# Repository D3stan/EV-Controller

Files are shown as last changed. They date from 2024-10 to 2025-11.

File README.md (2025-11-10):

# EV-Controller

This project is an ESP8266/ESP32-based exhaust valve controller for motorcycles. It offers real-time monitoring and configuration through a web interface, utilizing WebSockets for live data communication. The core functionality is to control the motorcycle's exhaust valve based on configurable RPM thresholds.

<table>
  <tr>
    <td>
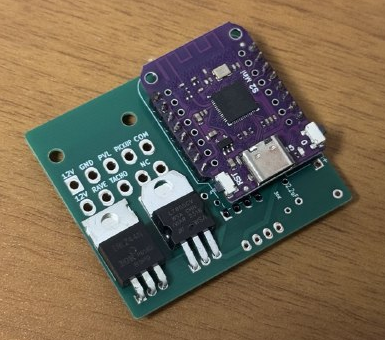
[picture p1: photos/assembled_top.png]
      <br>
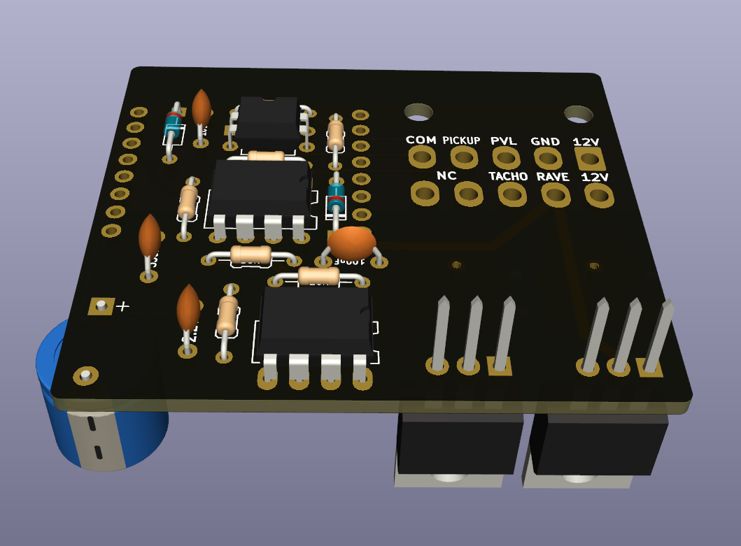
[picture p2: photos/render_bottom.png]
      
    </td>
    <td>
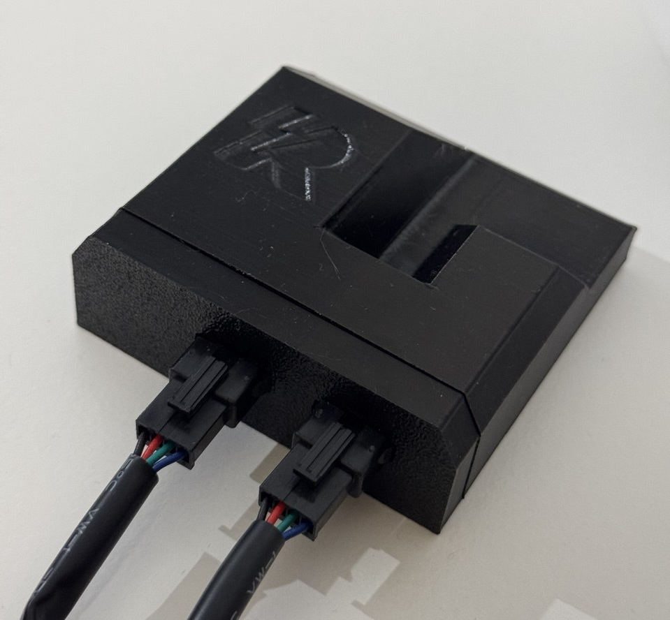
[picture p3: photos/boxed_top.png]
      
    </td>
  </tr>
</table>

## Features

- RPM-based exhaust valve control with configurable opening and closing thresholds.
- Web interface for real-time RPM monitoring and settings adjustment.
- WiFi Access Point (AP) mode for initial setup and configuration.
- WiFi Station (STA) mode to connect to an existing wireless network.
- Secure Over-the-Air (OTA) updates for both firmware and filesystem.
- Manual override for valve control directly from the web interface.

## Hardware Construction

To build the hardware, you will need to manufacture the PCB and source the electronic components.

### 1. PCB Manufacturing

The Gerber files required for PCB production are located in the `pcb/production/gerber.zip` archive. You can upload this file to any PCB manufacturer of your choice.

### 2. Component Sourcing

The list of all necessary components (Bill of Materials) is available in the `pcb/production/bom.csv` file. This file can be used to order parts from electronic component distributors.

### 3. Assembly

Solder the components onto the manufactured PCB. For component placement and orientation, please refer to the following files:

- **Schematic:** `pcb/schema.pdf`
- **KiCad Project:** `pcb/Rave-Controller.kicad_pro` (can be opened with KiCad)

For automated pick-and-place assembly, the `pcb/production/positions.csv` file is also provided.

## Firmware Installation

The firmware is built using PlatformIO.

### Prerequisites

- [Visual Studio Code](https://code.visualstudio.com/)
- [PlatformIO IDE extension](https://platformio.org/install/ide?install=vscode) for VS Code

### Build and Upload

1.  Clone this repository to your local machine.
2.  Open the cloned repository folder in Visual Studio Code.
3.  PlatformIO will automatically detect the `platformio.ini` file and prompt you to install the required project dependencies.
4.  Once dependencies are installed, select the correct environment for your board (e.g., `d1_mini`).
5.  Use the PlatformIO "Upload" task to build and flash the firmware to your device. Alternatively, you can run the following command from the integrated terminal:
    ```bash
    pio run -e d1_mini --target upload
    ```

## Initial Setup

1.  On the first boot, the device will create a Wi-Fi Access Point. The default SSID and password can be found in the source code (`data/config.json`).
2.  Connect your computer or smartphone to this Wi-Fi network.
3.  Open a web browser and navigate to the device's default IP address, which is `42.42.42.42`.
4.  From the web interface, you can configure your home Wi-Fi credentials (SSID and password) and set the desired RPM thresholds for the exhaust valve operation.
5.  After saving the new settings, the device will restart, connect to your specified Wi-Fi network, and begin normal operation.

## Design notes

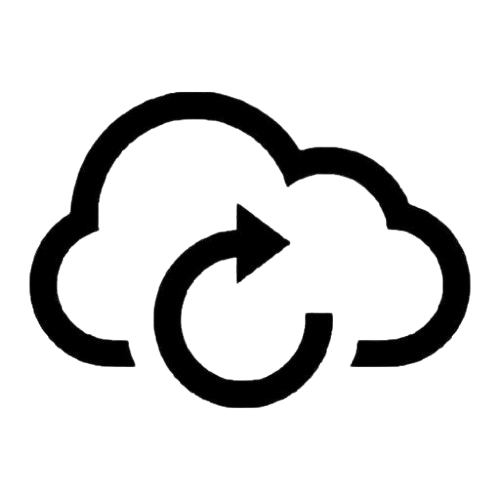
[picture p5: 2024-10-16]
docs/update.png

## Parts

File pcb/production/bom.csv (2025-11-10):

Designator | Footprint | Quantity | Value | LCSC Part #
C1, C5 | C_Disc_D4.3mm_W1.9mm_P5.00mm | 2 | 100nF
C2 | C_Disc_D4.3mm_W1.9mm_P5.00mm | 1 | 330nF
C3 | C_Disc_D4.3mm_W1.9mm_P5.00mm | 1 | 2.2uF
C4 | CP_Radial_D10.0mm_P7.50mm | 1 | 1000uF_50V
D1, D3 | D_DO-34_SOD68_P7.62mm_Horizontal | 2 | D_Schottky
J1 | Molex_Mini-Fit_Jr_5569-10A2_2x05_P4.20mm_Horizontal | 1 | Conn_01x10
Q1 | TO-220-3_Vertical | 1 | IRLZ44N
R1 | R_Axial_DIN0204_L3.6mm_D1.6mm_P7.62mm_Horizontal | 1 | 100k
R2 | R_Axial_DIN0204_L3.6mm_D1.6mm_P7.62mm_Horizontal | 1 | 1k
R3 | R_Axial_DIN0204_L3.6mm_D1.6mm_P7.62mm_Horizontal | 1 | 3k
R4, R7 | R_Axial_DIN0204_L3.6mm_D1.6mm_P7.62mm_Horizontal | 2 | 30k
R5 | R_Axial_DIN0204_L3.6mm_D1.6mm_P7.62mm_Horizontal | 1 | 4.7k
R6 | R_Axial_DIN0204_L3.6mm_D1.6mm_P7.62mm_Horizontal | 1 | 10k
U1 | D1_mini_board | 1 | D1Mini
U2 | TO-220-3_Vertical | 1 | LM7805_TO220
U3 | DIP-8_W7.62mm_LongPads | 1 | LMC662AIN
U4 | DIP-4_W7.62mm | 1 | PC817
U5 | DIP-8_W7.62mm | 1 | TC4422

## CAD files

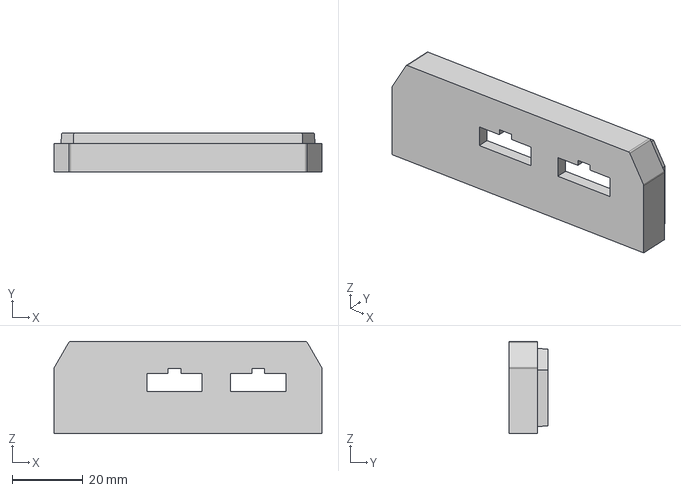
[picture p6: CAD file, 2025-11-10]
pcb/Rave v7.step
75.6 x 11.0 x 26.0 mm

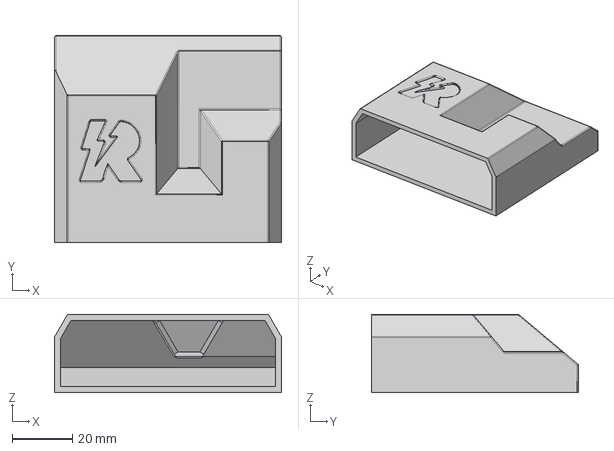
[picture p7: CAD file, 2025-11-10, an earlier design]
pcb/Rave v4.step
75.6 x 68.9 x 26.0 mm

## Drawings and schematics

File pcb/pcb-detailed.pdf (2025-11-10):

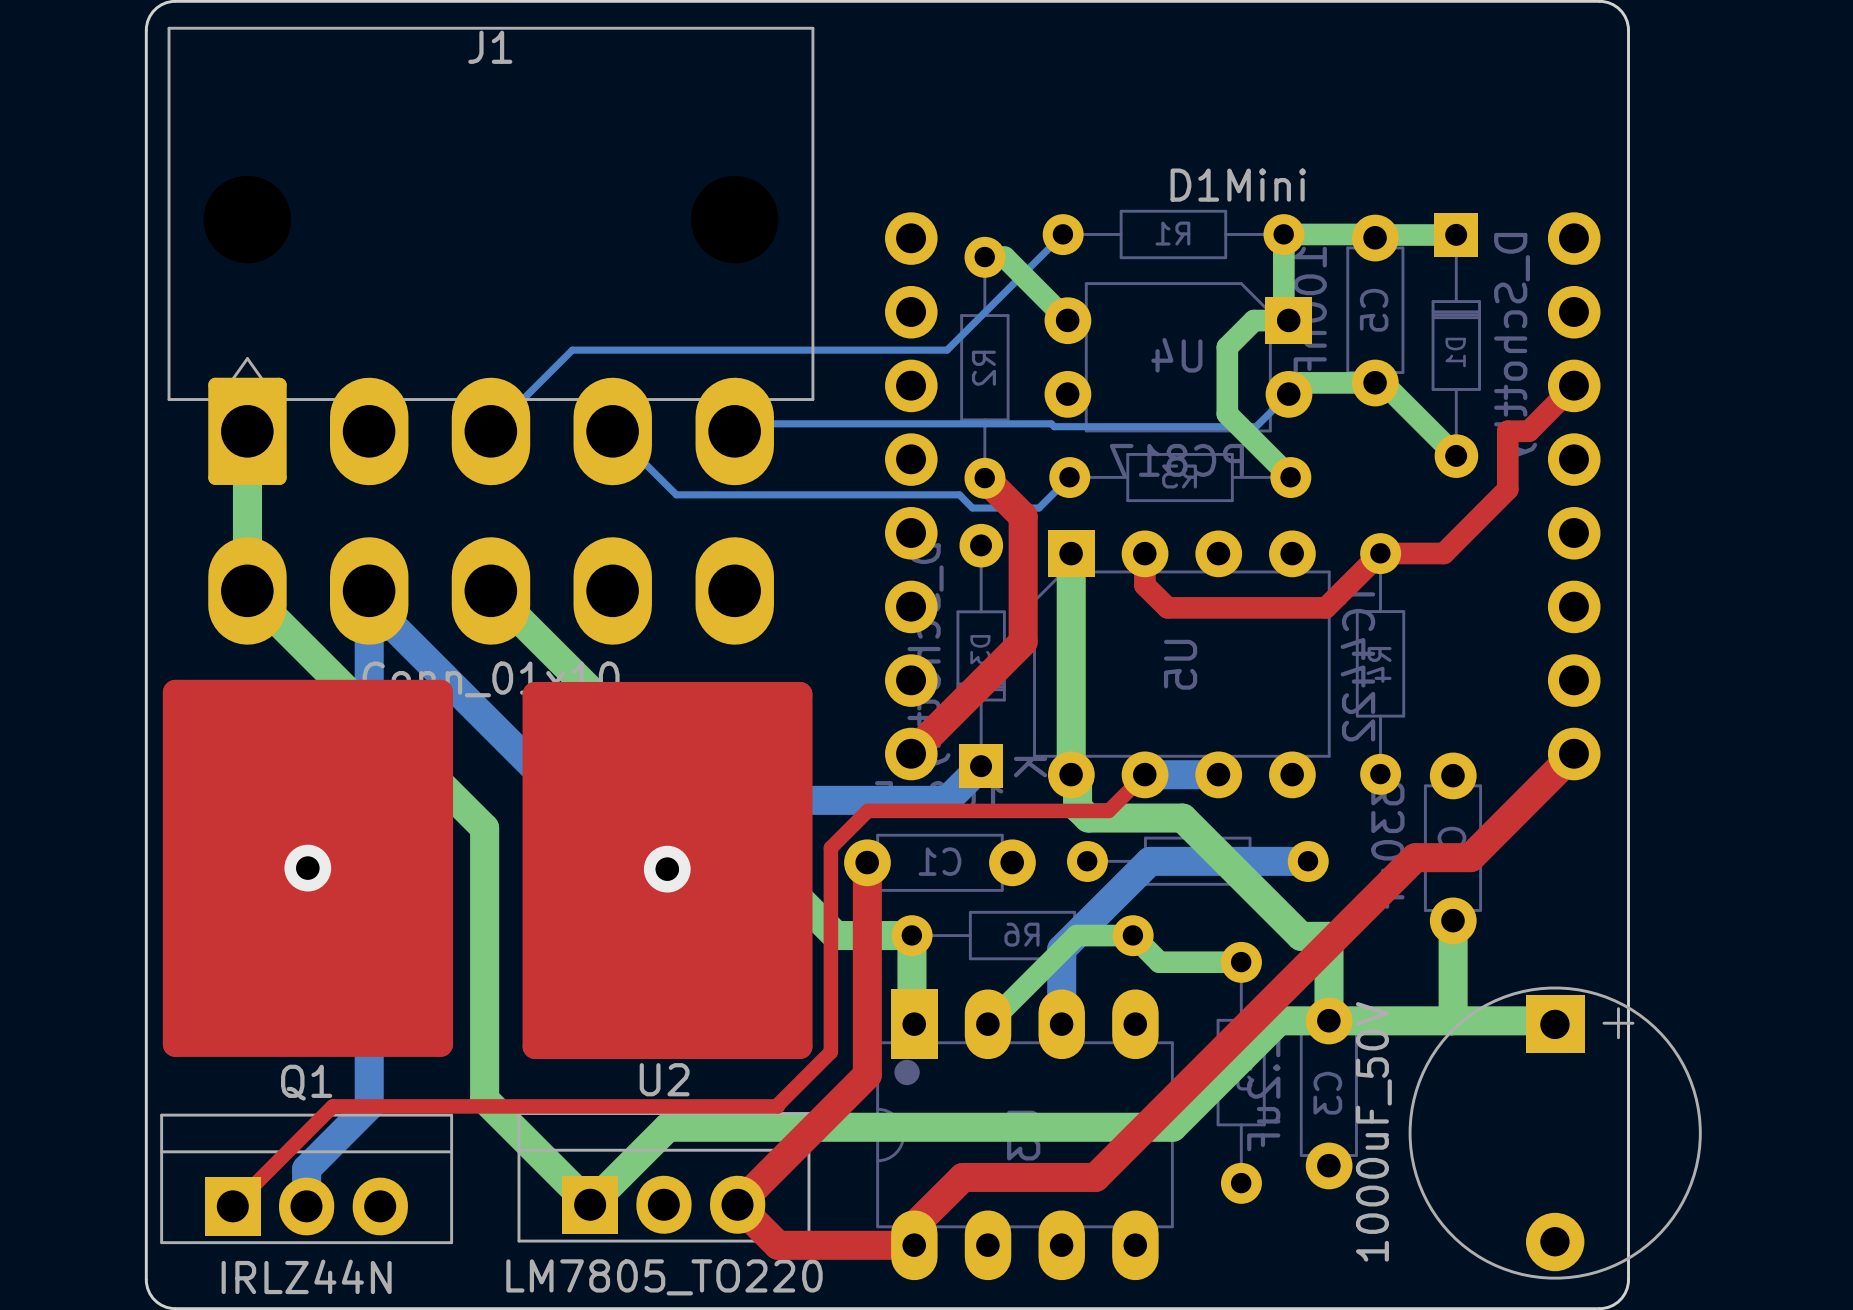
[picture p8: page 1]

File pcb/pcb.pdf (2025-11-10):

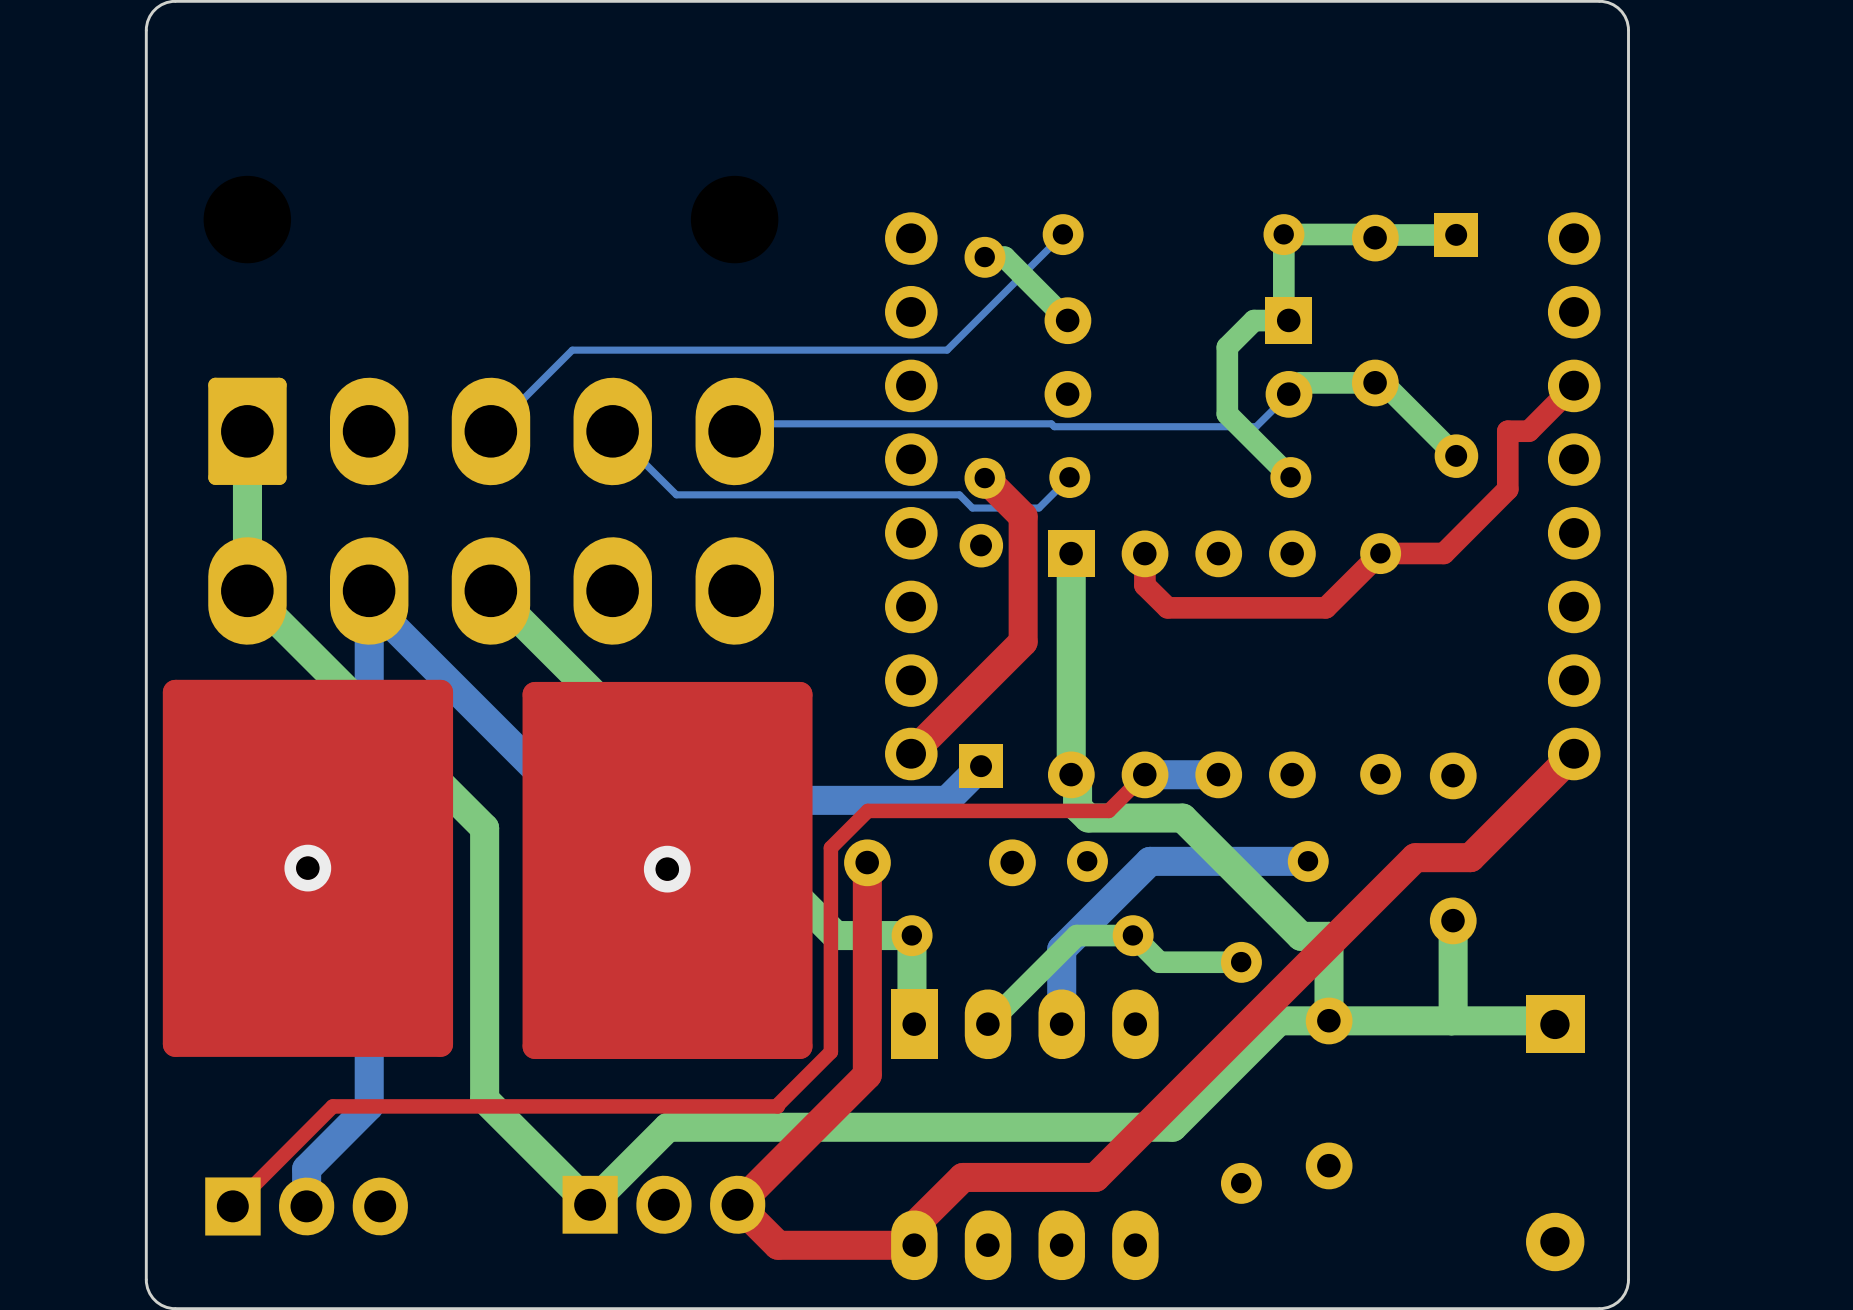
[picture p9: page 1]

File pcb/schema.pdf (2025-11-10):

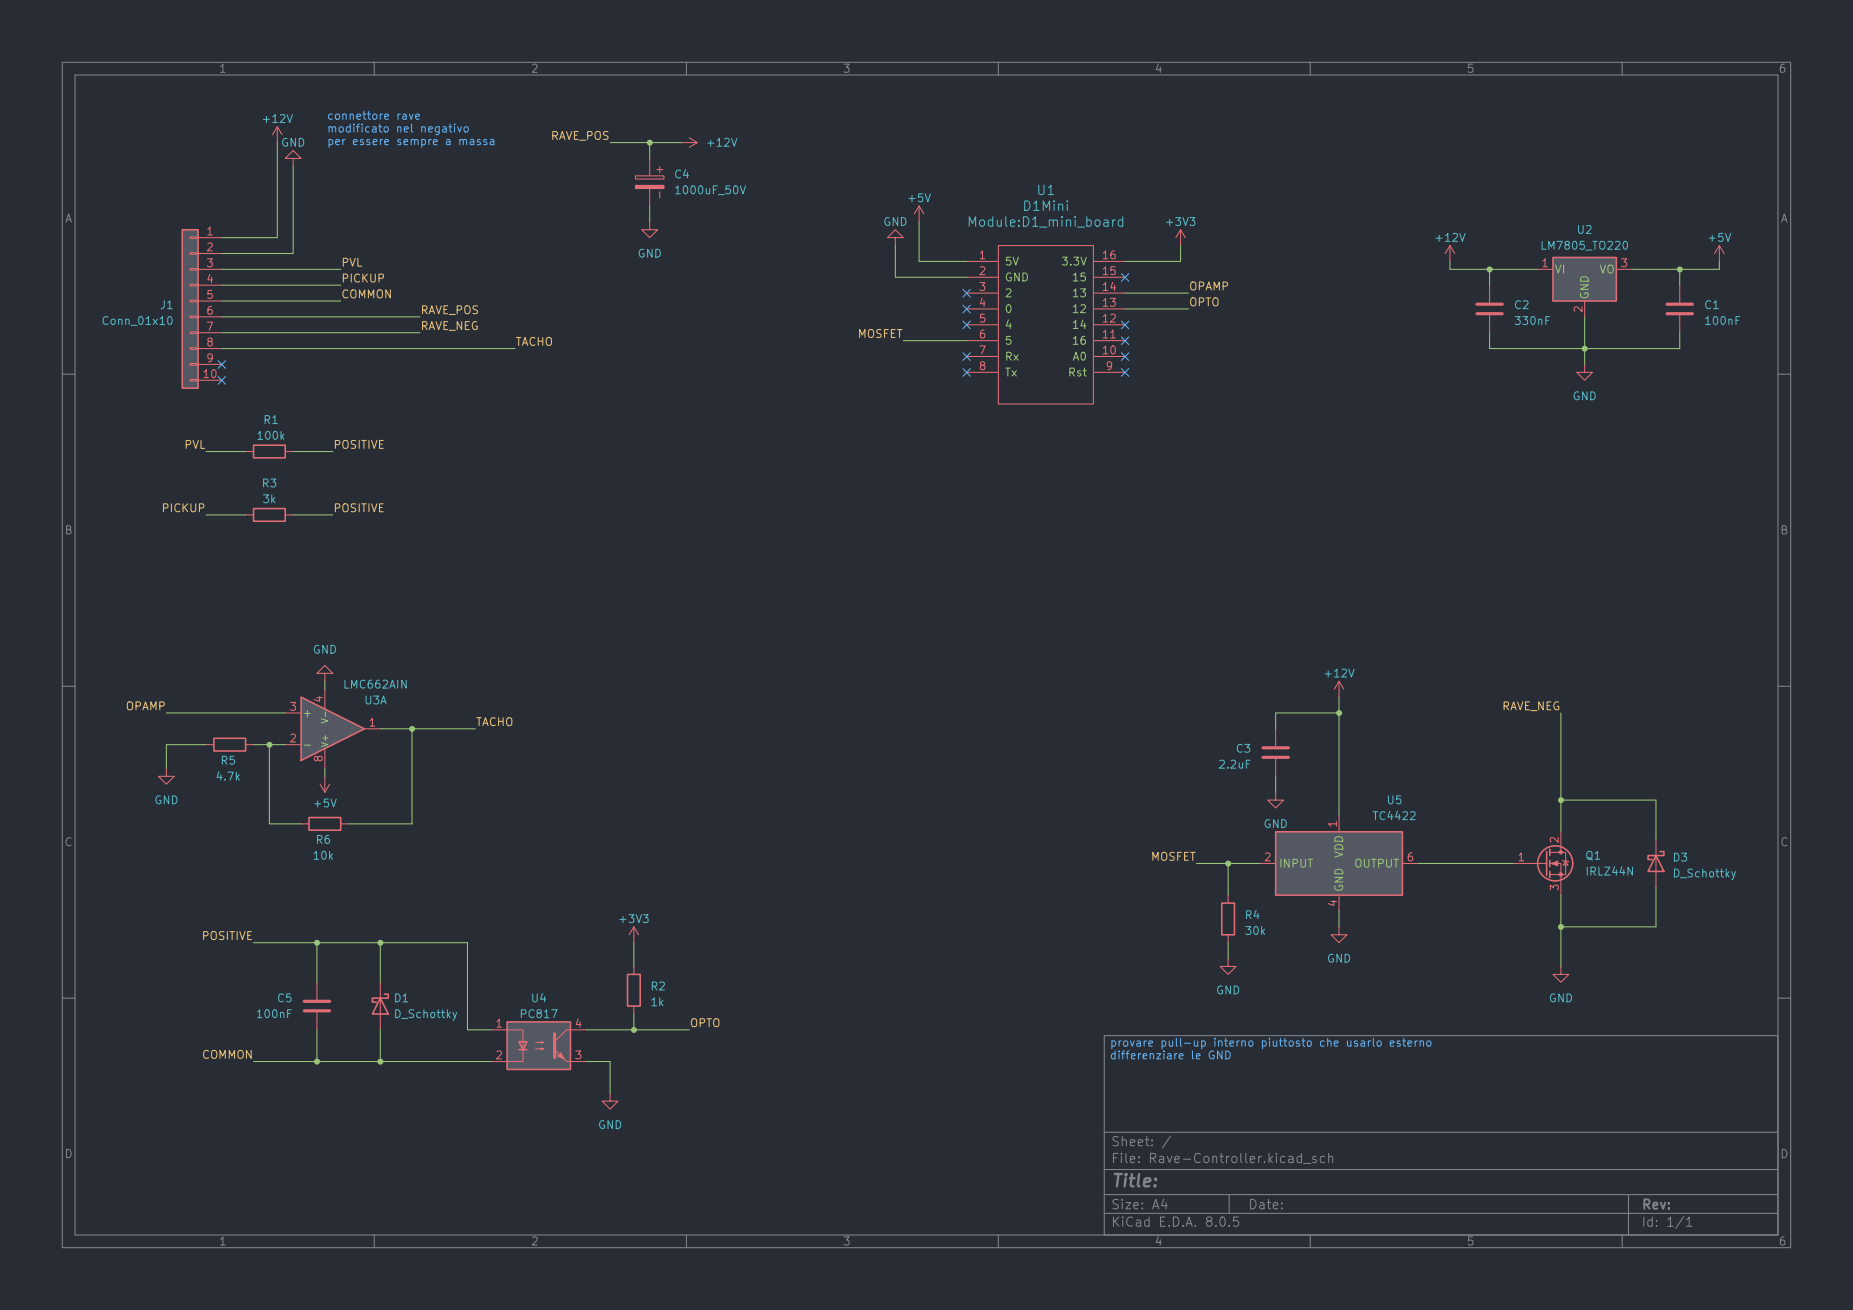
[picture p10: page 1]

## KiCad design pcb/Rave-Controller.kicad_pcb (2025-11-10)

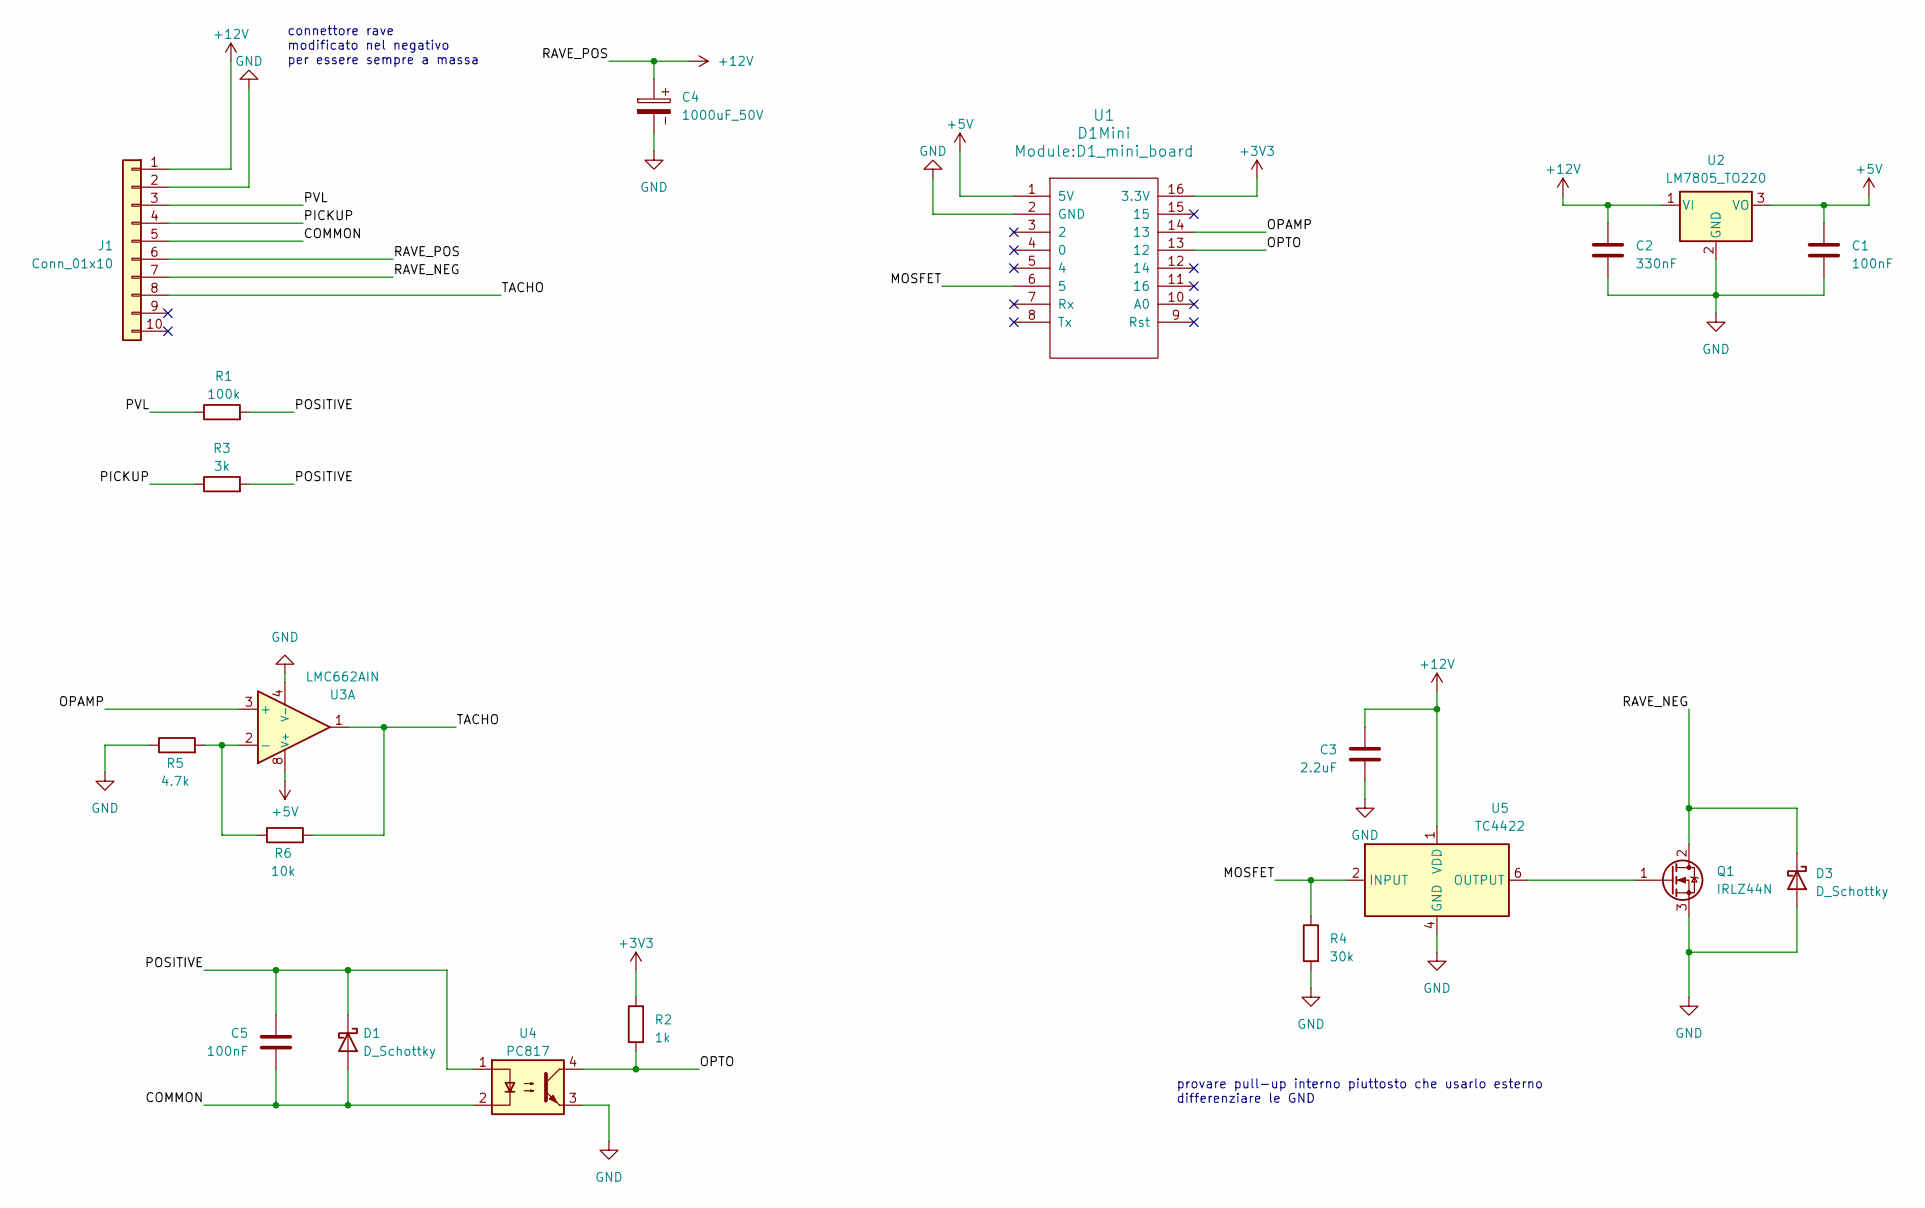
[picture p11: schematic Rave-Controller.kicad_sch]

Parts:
C1, C5: 100nF; C_Disc_D4.3mm_W1.9mm_P5.00mm
C2: 330nF; C_Disc_D4.3mm_W1.9mm_P5.00mm
C3: 2.2uF; C_Disc_D4.3mm_W1.9mm_P5.00mm
C4: 1000uF_50V; CP_Radial_D10.0mm_P7.50mm
D1, D3: D_Schottky; D_DO-34_SOD68_P7.62mm_Horizontal
J1: Conn_01x10; Molex_Mini-Fit_Jr_5569-10A2_2x05_P4.20mm_Horizontal
Q1: IRLZ44N; TO-220-3_Vertical
R1: 100k; R_Axial_DIN0204_L3.6mm_D1.6mm_P7.62mm_Horizontal
R2: 1k; R_Axial_DIN0204_L3.6mm_D1.6mm_P7.62mm_Horizontal
R3: 3k; R_Axial_DIN0204_L3.6mm_D1.6mm_P7.62mm_Horizontal
R4: 30k; R_Axial_DIN0204_L3.6mm_D1.6mm_P7.62mm_Horizontal
R5: 4.7k; R_Axial_DIN0204_L3.6mm_D1.6mm_P7.62mm_Horizontal
R6: 10k; R_Axial_DIN0204_L3.6mm_D1.6mm_P7.62mm_Horizontal
U1: D1Mini; D1_mini_board
U2: LM7805_TO220; TO-220-3_Vertical
U3: LMC662AIN; DIP-8_W7.62mm_LongPads
U4: PC817; DIP-4_W7.62mm
U5: TC4422; DIP-8_W7.62mm

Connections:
+3V3: R2.1, U1.16 (3.3V)
+5V: C1.1, U1.1 (5V), U2.3 (VO), U3.8 (V+)
+12V: C2.1, C3.2, C4.1, J1.1, J1.6, U2.1 (VI), U5.1 (VDD), U5.8 (VDD)
/COMMON: C5.1, D1.2 (A), J1.5, U4.2
/MOSFET: R4.1, U1.6 (5), U5.2 (INPUT)
/OPAMP: U1.14 (13), U3.3 (+); also elsewhere on the board
/OPTO: R2.2, U1.13 (12), U4.4
/PICKUP: J1.4, R3.1
/POSITIVE: C5.2, D1.1 (K), R1.2, R3.2, U4.1
/PVL: J1.3, R1.1
/RAVE_NEG: D3.1 (K), J1.7, Q1.2 (D)
/TACHO: J1.8, R6.2, U3.1
GND: C1.2, C2.2, C3.1, C4.2, D3.2 (A), J1.2, Q1.3 (S), R4.2, R5.1, U1.2 (GND), U2.2 (GND), U3.4 (V-), U4.3, U5.4 (GND), U5.5 (GND); also elsewhere on the board
unnamed: Q1.1 (G), U5.6 (OUTPUT), U5.7 (OUTPUT)
unnamed: R5.2, R6.1, U3.2 (-)

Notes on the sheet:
connettore rave modificato nel negativo per essere sempre a massa
provare pull-up interno piuttosto che usarlo esterno differenziare le GND

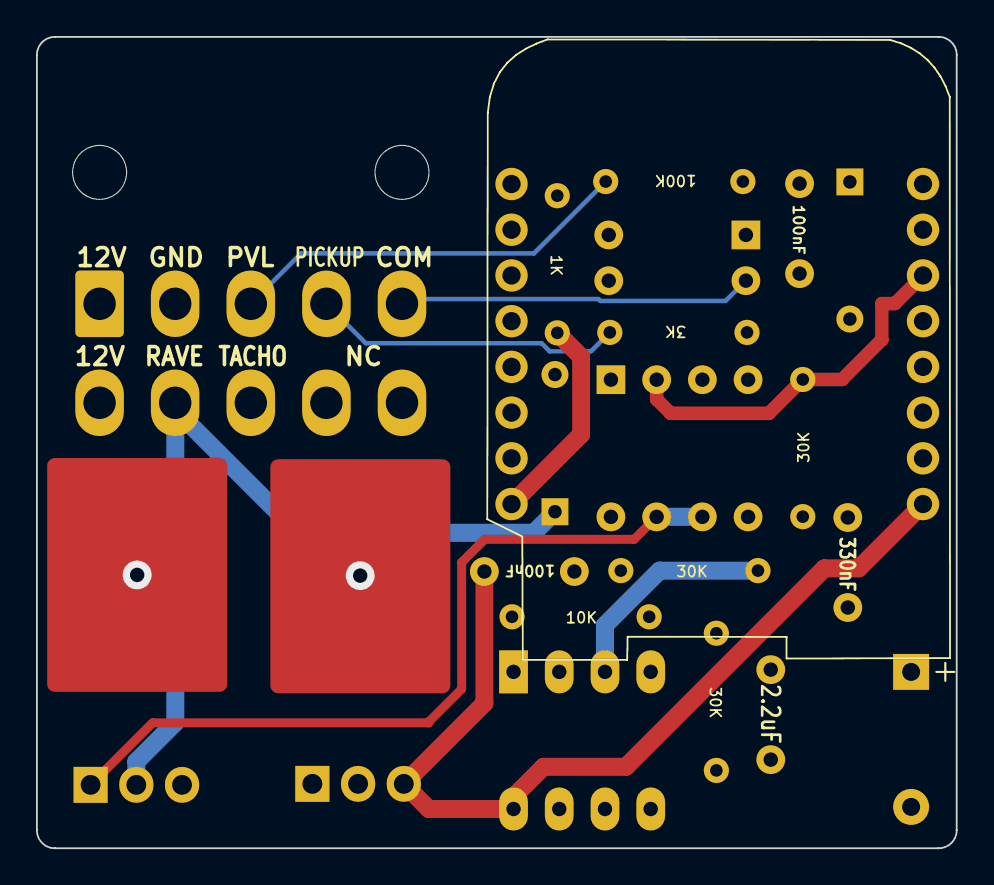
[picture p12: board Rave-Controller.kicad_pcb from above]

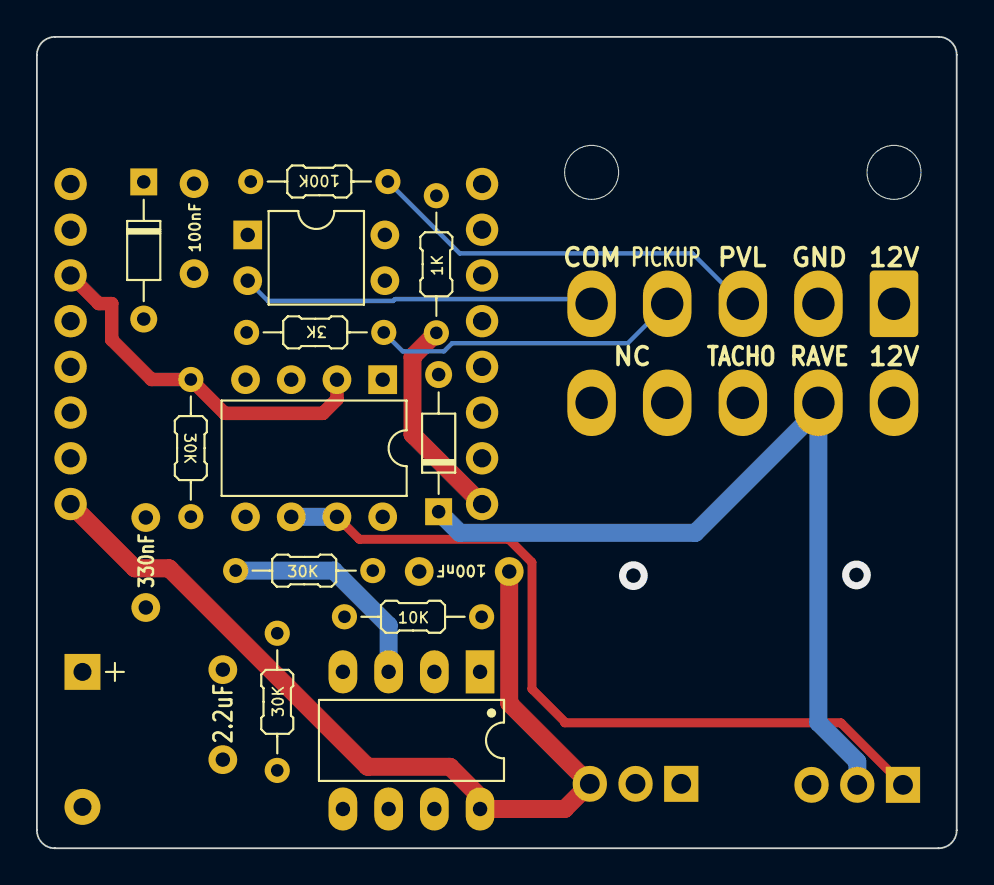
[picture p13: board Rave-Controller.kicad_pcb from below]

Board: 4 copper layers, 51.1 x 45.1 mm, 21 parts (16 on the bottom side), 15 nets.

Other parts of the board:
R7: 30k; R_Axial_DIN0204_L3.6mm_D1.6mm_P7.62mm_Horizontal

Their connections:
/OPAMP: R7.1; also elsewhere on the board
GND: R7.2; also elsewhere on the board

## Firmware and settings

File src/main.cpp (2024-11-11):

#include "Commons.h"
#include "update.h"
#include "utils.h"
#include "webserver.h"
#include "websocket.h"
#include "wifi.h"
#include "rave.h"
#include "vars.h"
#include "cert.h"
#include "notfound.h"

// ----------------------------------------------------------------------------
// Definition of global constants
// ----------------------------------------------------------------------------



Config config;

bool raveManualOpen = false;
bool raveOpen = false;
bool FSmounted = false;


// Rpm count
int RPM = 0;
unsigned long currentMillis = 0;
unsigned long currentMicros = 0;
unsigned long lastMicros = 0;
unsigned long displayMillis = 0;
unsigned long checkEngineMillis = 0;


// ----------------------------------------------------------------------------
// Definition of the LED component
// ----------------------------------------------------------------------------

struct Led {
    // state variables
    uint8_t pin;
    bool    on;

    // methods
    void update() {
        digitalWrite(pin, on ? HIGH : LOW);
    }
};


// I/O
Led    onboard_led = { LED_BUILTIN, true };


// ----------------------------------------------------------------------------
// Interrupt for RPM measurement
// ----------------------------------------------------------------------------

IRAM_ATTR void signalDetected() {
    currentMicros = micros();

    if (lastMicros != currentMicros && (currentMicros - lastMicros) >= 500) {
        RPM = 60000000 / (currentMicros - lastMicros);
        lastMicros = currentMicros;
    }

}



// ----------------------------------------------------------------------------
// Filesystem
// ----------------------------------------------------------------------------



void initFS() {
    if (!LittleFS.begin()) {
        Serial.println("An error has occurred while mounting LittleFS");
        FSmounted = false;
        return;
    }

    FSmounted = true;
    loadConfiguration(config_file_path, config);
    saveConfiguration(config_file_path, config); // update fwid
}

void initGPIO() {
    pinMode(onboard_led.pin, OUTPUT);
    pinMode(valveOut,        OUTPUT);
    pinMode(tachoOut,        OUTPUT);
    pinMode(inductiveIn,      INPUT);
    attachInterrupt(digitalPinToInterrupt(inductiveIn), signalDetected, FALLING);

    #if defined(ESP8266)
        analogWriteRange(255);
        analogWriteFreq(800);
    #elif defined(ESP32)
        //ledcSetup(0, 500, 8);
        //ledcAttachPin(VALVE_OUT, 0);
    #endif

    Serial.begin(115200);
}


// ----------------------------------------------------------------------------
// Initialization
// ----------------------------------------------------------------------------

void setup() {
    initGPIO();
    for (int i = 0; i < 5; i++) {
        Serial.printf("\n.");
        delay(1000);
    }
    initHwid();
    initFS();
    initWiFi();
    initWebSocket();
    initWebServer();
}

// ----------------------------------------------------------------------------
// Main control loop
// ----------------------------------------------------------------------------

void loop() {
    currentMillis = millis();
    onboard_led.on = currentMillis % 1000 < 500;
    if (currentMillis - displayMillis >= 35) updateRPM(RPM);
    if (currentMillis - checkEngineMillis >= 20) {
        checkIfEngineRunnig(currentMillis);
        setValveState(RPM);
    }

    // ArduinoOTA.handle();
    onboard_led.update();
    ws.cleanupClients();
    
    handlehostname();
    
}

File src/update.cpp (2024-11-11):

#include "update.h"

#if defined(ESP8266)
    X509List cert(IRG_Root_X1);
#endif

Ticker updateTimer;

// ----------------------------------------------------------------------------
// Remote Update Utils
// ----------------------------------------------------------------------------

void update_started() {
  Serial.println("CALLBACK:  HTTP update process started");
}

void update_finished() {
  Serial.println("CALLBACK:  HTTP update process finished");
}

void update_progress(int cur, int total) {
  Serial.printf("CALLBACK:  HTTP update process at %d of %d bytes...\n", cur, total);
}

void update_error(int err) {
  Serial.printf("CALLBACK:  HTTP update fatal error code %d\n", err);
}


void checkForUpdate(bool firstTime) {
    if (WiFi.status() != WL_CONNECTED) {
        Serial.println("Not connected");
        return;
    }

    // http client created outside from the HTTPupdate request so
    // we can add custom headers
    WiFiClientSecure wifiClient;
    HTTPClient httpClient;

    #if defined(ESP8266)
        wifiClient.setTrustAnchors(&cert);
    #elif defined(ESP32)
        wifiClient.setCACert(IRG_Root_X1);
    #endif

    // HTTPupdate class does this automatically if we pass the wificlient
    // in this case we are passing it the http client so
    // we have to manually begin the req
    httpClient.begin(wifiClient, update_server_url);  // Start connection to the server
    httpClient.setTimeout(httpTimeout);

    // Add security headers
    httpClient.addHeader("hwid", config.hwid);     // HTTPupdate class adds ESP.getChipId() in the x-ESP8266-Chip-ID header

    // Add functionality headers
    httpClient.addHeader("fwid", config.fw_version);
    httpClient.addHeader("fsid", config.fs_version);
    httpClient.addHeader("device", device);
    httpClient.addHeader("platform", platform);
    httpClient.addHeader("mode", firstTime ? "firmware" : "filesystem");
    

    #if defined(ESP8266)
        ESP8266HTTPUpdate myESPhttpUpdate;
    #elif defined(ESP32)
        HTTPUpdate myESPhttpUpdate;
    #endif
    

    // Remove automatic reboot
    myESPhttpUpdate.rebootOnUpdate(false);
    // Add optional led flashing
    myESPhttpUpdate.setLedPin(LED_BUILTIN, LOW);

    // Add optional callback notifiers
    myESPhttpUpdate.onStart(update_started);
    myESPhttpUpdate.onEnd(update_finished);
    myESPhttpUpdate.onProgress(update_progress);
    myESPhttpUpdate.onError(update_error);

    Serial.println("Starting update from: " + String(update_server_url));
    #if defined(ESP8266)
        t_httpUpdate_return ret = firstTime ? myESPhttpUpdate.update(httpClient) : myESPhttpUpdate.updateFS(httpClient);
    #elif defined(ESP32)
        t_httpUpdate_return ret = firstTime ? myESPhttpUpdate.update(httpClient) : myESPhttpUpdate.updateSpiffs(httpClient);
    #endif
    

    if (ret == HTTP_UPDATE_FAILED) {
        Serial.printf("HTTP_UPDATE_FAILED Error (%d): %s\n", myESPhttpUpdate.getLastError(), myESPhttpUpdate.getLastErrorString().c_str());
        char err[100];
        sprintf(err, "Update Failed: %s", myESPhttpUpdate.getLastErrorString().c_str());
        config.lastMessage = err;
        config.wifiMode = WIFI_AP;
        saveConfiguration(config_file_path, config);
        delay(1500);
        ESP.restart();

    } else {
        if (ret == HTTP_UPDATE_NO_UPDATES) {
            Serial.println("No updates available");
        } else {
            Serial.printf("Update %s successfully", firstTime ? "firmware" : "filesystem");
        }

        if (firstTime) {
            httpClient.end();
            wifiClient.stop();
            checkForUpdate(false);
        }
        else {
            config.wifiMode = WIFI_AP;
            saveConfiguration(config_file_path, config);
            delay(1500);
            ESP.restart();
        }
    }

}

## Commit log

2024-10-26 small fix pre test
    [main.cpp]
2024-10-26 esp32 compatibility
2024-10-27 new config struct, working base mcu, need to add general checks and a system to handle updating error in STA mode (should reboot in AP and display the error)
    [main.cpp]
2024-10-27 http update error handling
    [main.cpp]
2024-10-27 tested but might have some bugs somewhere, overall works update and error messages
    [main.cpp]
2024-10-28 fixed reboot update crash using Ticker
    [main.cpp]
2024-10-28 fix header files and added rave file
    [main.cpp, websocket.cpp, wifi.cpp]
2024-10-28 strange crash when connecting, happens only in release mode (not debug)
    [main.cpp, rave.cpp]
2024-10-29 Crash problem: crashes only in release mode (debug works fine)
    [main.cpp, rave.cpp]
2024-10-30 fixed but without dns
    [main.cpp, rave.cpp, websocket.cpp]
2024-10-31 added hysteresis time control, other minor fixed (VERSION NOT TESTED)
    [rave.cpp, utils.cpp, websocket.cpp]
2024-11-01 fixed string conversion problem, working and updated with lastMessage function
    [main.cpp, update.cpp, utils.cpp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]
2024-11-01 tested with small solenoid and AWG, working, then added manual rave operation (UNTESTED)
2025-11-10 added documentation and PCB schematic
    [Rave v4.step, Rave v7.step, Rave-Controller.kicad_pcb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]
